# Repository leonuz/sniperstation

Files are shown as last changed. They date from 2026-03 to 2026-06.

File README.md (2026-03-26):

# SniperStation

Automatic irrigation system and weather station for two succulent planters located outdoors in Orlando, Florida.

**SucuFer** — Fernanda's succulent, planted April 22, 2024
**SucuRod** — Rodrigo's succulent, planted April 22, 2024

Monitors environmental conditions (temperature, humidity, light, soil moisture) and waters automatically based on sensor readings. Provides a color touchscreen dashboard (CYD), web dashboard (Grafana), Telegram push alerts, and full historical data logging.

---

## System Overview

```
[OUTSIDE]                                   [INSIDE]
Station-485 (main controller)               CYD ESP32-2432S028 x2
├── BH1750 light sensor    → Port A1        ├── Master Bedroom (SHT30 on CN1)
├── SHT30 outdoor          → Port A2        └── Kids Bedroom   (SHT30 on CN1)
├── Earth Sensor SucuFer   → Port B1                │
├── Earth Sensor SucuRod   → Port B2                │
├── Relay → Pump SucuFer   → Port C1                │
├── Relay → Pump SucuRod   → Port C2                │
└── XKC-Y25 water level    → Port B/C               │
          │                                         │
          └────────── WiFi → MQTT ──────────────────┘
                            │
                     [Proxmox LXC]
                     ├── Mosquitto (MQTT broker)
                     ├── InfluxDB 2.x (time-series database)
                     ├── Grafana (web/mobile dashboard)
                     └── Telegram Bot (push alerts)
```

---

## The Plants

| Plant | Owner | Age | Planted |
|---|---|---|---|
| SucuFer | Fernanda | ~2 years | April 22, 2024 |
| SucuRod | Rodrigo | ~2 years | April 22, 2024 |

The CYD touchscreen detail view for each plant displays the owner's photo with their succulent as the background, along with planting date and current soil moisture.

---

## Hardware Requirements

| Component | Model | Status |
|---|---|---|
| Main controller | M5Stack Station-485 | Have it |
| Light sensor | DLight BH1750 | Have it |
| Temp/humidity x2 | SHT30 IOT-TH02 | Purchased |
| Grove↔Dupont cable | HY2.0-4P to 2.54mm | Purchased |
| Peristaltic pumps x2 | DC 12-24V, 80mA | Purchased — arriving late April |
| Water level sensor | XKC-Y25-V + DFRobot driver | Purchased |
| Soil sensors x2 | M5Stack Earth Sensor | Purchased |
| Relay modules x2 | M5Stack Mini 3A Relay | Purchased |
| Indoor display x2 | CYD ESP32-2432S028 | Purchased — arriving Saturday |
| DC adapter | 12V 2A, 5.5mm jack | **Pending purchase** |
| Outdoor enclosure | IP65+, ventilated | **Pending purchase** |
| Indoor enclosure x2 | Custom 3D printed | **Pending design** |

Full BOM → [hardware/BOM.md](hardware/BOM.md)

---

## Software Stack

| Service | Port | Role |
|---|---|---|
| Mosquitto | 1883 | MQTT broker |
| InfluxDB 2.x | 8086 | Time-series database |
| Grafana | 3000 | Web/mobile dashboard |
| Telegram Bot | — | Push notifications |

All services run in a single Proxmox LXC container.

---

## Repository Structure

```
sniperstation/
├── hardware/
│   ├── BOM.md                        # Full bill of materials
│   ├── schematics/                   # Wiring diagrams
│   ├── datasheets/                   # Component datasheet references
│   └── enclosure/                    # Enclosure specifications + OpenSCAD
├── firmware/
│   ├── station485/                   # Arduino IDE — ESP32 (Station-485)
│   └── cyd_indoor/                   # Arduino IDE — CYD ESP32 (indoor x2)
├── software/
│   ├── mosquitto/                    # Broker config
│   ├── influxdb/                     # Database setup
│   ├── grafana/                      # Dashboard JSON exports
│   └── telegram_bot/                 # Alert bot
├── assets/
│   └── photos/                       # SucuFer + SucuRod plant photos (CYD backgrounds)
├── README.md
├── ROADMAP.md
├── TODO.md
└── CHANGELOG.md
```

---

## Irrigation Logic

```
Every 6 hours (via RTC BM8563):
  FOR each plant (SucuFer, SucuRod):
    IF soil_moisture < dry_threshold:
      IF air_humidity < 85% (not raining):
        IF water_available == TRUE:
          activate_pump(plant, 20 seconds)   // ~33ml at 100ml/min
          wait 30 minutes
          re-read soil_moisture
          IF still_dry: send Telegram alert
        ELSE:
          send Telegram alert "Water tank empty"
```

Pump flow reference: ~100 ml/min at 12V → 20 seconds = ~33 ml

---

## Soil Moisture Thresholds (calibrate with actual planters)

| State | Range | Action |
|---|---|---|
| Dry | < 30% | Irrigate |
| Moist | 30–60% | No action |
| Wet | > 60% | Alert — overwatering risk |

---

## Telegram Alerts

- Irrigation executed (SucuFer / SucuRod + ml delivered)
- Water tank empty
- Soil dry for more than 24h
- Outdoor temperature > 38°C (Orlando extreme heat)
- Sensor disconnected / read error

---

## CYD Touchscreen UI

| View | Content |
|---|---|
| Screensaver | Logo + compact temp summary all rooms |
| Main view | All sensors: exterior + master + kids + SucuFer + SucuRod |
| SucuFer detail | Fernanda's photo background + soil moisture + last watered + plant age |
| SucuRod detail | Rodrigo's photo background + soil moisture + last watered + plant age |

---

## Important Notes

### Orlando Heat
Station-485 max operating temperature is **60°C**. In direct Florida summer sun, enclosures can exceed this easily.
**Mandatory:** install in shade + passive or active ventilation. A 5V fan from inventory can be added if needed.

### GPIO Constraint — Port B2
Uses ESP32 GPIO G36, which **cannot be configured as OUTPUT**.
Earth Sensor SucuRod is read-only (analog input) — correct for this use case.
**Never connect a relay to Port B.**

### I2C Shared Bus (Ports A1/A2)
BH1750 (address 0x23) and SHT30 (address 0x44) share the same I2C bus on G32/G33.
Different addresses — no conflict.

---

## License

Open Hardware — CERN OHL v2 Permissive
Software — MIT

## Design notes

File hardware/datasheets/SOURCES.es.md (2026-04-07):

# Fuentes de Datasheets — SniperStation

Documentación oficial y datasheets de todos los componentes usados en este proyecto.

---

## Controlador Principal

### M5Stack Station-485
- **Página del producto:** https://docs.m5stack.com/en/base/station_485
- **Datasheet ESP32-D0WDQ6:** https://www.espressif.com/sites/default/files/documentation/esp32_datasheet_en.pdf
- **Manual técnico ESP32:** https://www.espressif.com/sites/default/files/documentation/esp32_technical_reference_manual_en.pdf
- **Datasheet RTC BM8563:** https://www.nxp.com/docs/en/data-sheet/PCF8563.pdf *(BM8563 es compatible con PCF8563)*

---

## Sensores

### DLight BH1750 — Sensor de Luz
- **Datasheet:** https://www.mouser.com/datasheet/2/348/bh1750fvi-e-186247.pdf
- **Dirección I2C:** 0x23 (ADDR bajo) / 0x5C (ADDR alto)
- **Especificación clave:** 1–65535 lx, resolución de 16 bits

### SHT30 IOT-TH02 — Temperatura y Humedad
- **Datasheet Sensirion SHT30:** https://sensirion.com/media/documents/213E6A3B/63A5A569/Datasheet_SHT3x_DIS.pdf
- **Dirección I2C:** 0x44 (ADDR bajo) / 0x45 (ADDR alto)
- **Especificaciones clave:** Temp ±0.3°C, Humedad ±2% RH, alimentación 2.15–5.5V

### M5Stack Earth Sensor — Humedad de Suelo
- **Página del producto:** https://docs.m5stack.com/en/unit/earth
- **Salida:** Analógica (0–3.3V) + digital de umbral (ajustable por potenciómetro)
- **Nota clave:** Requiere calibración con el tipo de suelo real

### XKC-Y25-V — Sensor de Nivel de Agua Sin Contacto
- **Página del producto XKC-Y25-V:** https://www.xkc.com.cn/en/product/XKC-Y25-V.html
- **Wiki DFRobot:** https://wiki.dfrobot.com/Non-contact_Liquid_Level_Sensor_XKC-Y25_T12V_SKU__SEN0204
- **Especificaciones clave:** 5–24V, salida digital, funciona en paredes de plástico/vidrio ≤ 3mm, 4 niveles de sensibilidad

---

## Actuadores

### M5Stack Mini Relay 3A
- **Página del producto:** https://docs.m5stack.com/en/unit/mini_relay
- **Especificaciones clave:** 3A/30VDC, 3A/125VAC, control Grove HY2.0, LOW = OFF, HIGH = ON

### Bomba Peristáltica 12V DC
- El datasheet varía según el proveedor. Especificaciones clave verificadas:
  - Voltaje de operación: 12–24V DC
  - Caudal: ~100 ml/min a 12V
  - Corriente: ~80mA a 12V
  - Reversible por inversión de polaridad
  - Tuberías: silicona, aptas para alimentos

---

## Controlador Interior

### ESP8266 NodeMCU CP2102 (ESP-12E)
- **Datasheet ESP8266:** https://www.espressif.com/sites/default/files/documentation/0a-esp8266ex_datasheet_en.pdf
- **Referencia técnica ESP8266:** https://www.espressif.com/sites/default/files/documentation/esp8266-technical_reference_en.pdf
- **Referencia pinout NodeMCU:** https://components101.com/development-boards/nodemcu-esp8266-pinout-features-and-datasheet
- **Bridge USB-UART CP2102:** https://www.silabs.com/documents/public/data-sheets/CP2102-9.pdf

---

## Componentes de Soporte

### Diodo Rectificador 1N4007 (protección flyback)
- **Datasheet:** https://www.vishay.com/docs/88503/1n4007.pdf
- **Uso:** Diodo flyback/freewheeling en cargas inductivas (motores de bomba)

### L293D H-Bridge Motor Driver (opcional — bombas reversibles)
- **Datasheet:** https://www.ti.com/lit/ds/symlink/l293d.pdf
- **Uso:** Si se necesita control bidireccional de bomba (drenar tuberías después del riego)

### MCP3008 ADC (opcional — expansión)
- **Datasheet:** https://ww1.microchip.com/downloads/en/DeviceDoc/21295d.pdf
- **Uso:** ADC SPI de 8 canales y 10 bits para ampliar entradas analógicas

---

## Referencias de Software / Protocolo

### Protocolo MQTT
- **Especificación MQTT 3.1.1:** https://docs.oasis-open.org/mqtt/mqtt/v3.1.1/os/mqtt-v3.1.1-os.html

### InfluxDB 2.x
- **Documentación:** https://docs.influxdata.com/influxdb/v2/

### Grafana
- **Documentación:** https://grafana.com/docs/grafana/latest/

### Mosquitto MQTT Broker
- **Documentación:** https://mosquitto.org/documentation/

---

## Estándares Referenciados

| Estándar | Descripción |
|---|---|
| CERN OHL v2 Permissive | Licencia de hardware abierto usada en este proyecto |
| Especificación I2C | https://www.nxp.com/docs/en/user-guide/UM10204.pdf |
| Estándar conector Grove | HY2.0-4P, paso 2mm, orden de pines: GND/VCC/GPIO_B/GPIO_A |

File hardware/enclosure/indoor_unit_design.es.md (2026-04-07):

# Unidad Interior — Especificación de Enclosure

**Unidades:** 2 (idénticas — Habitación Principal + Habitación de los Niños)
**Material:** PLA (estándar, suficiente para uso interior)
**Montaje:** Montaje en pared
**Color de impresión:** Blanco o gris claro recomendado (combina con la carcasa del SHT30)

---

## Componentes a Alojar

| Componente | Dimensiones PCB | Notas |
|---|---|---|
| ESP8266 NodeMCU CP2102 | 49 x 26 x 12mm | Micro-USB en el extremo corto (inferior) |
| OLED SSH1106 1.3" | 38.5 x 23 x 4mm | Visible a través de la ventana frontal |
| Sensor táctil TTP223 | 24 x 14 x 3mm | Accesible a través del orificio frontal |
| SHT30 (con carcasa) | ~35 x 20 x 12mm | Se monta en la parte superior, expuesto al aire |

---

## Dimensiones Externas

```
Ancho:  70mm
Alto:   90mm  (sin contar el SHT30 en la parte superior)
Fondo:  36mm
Pared:   2mm
```

---

## Distribución de la Cara Frontal

```
         70mm
┌─────────────────────┐  ─┐
│    ┌───────────┐    │   │  14mm margen superior
│    │  [OLED]   │    │   │  Ventana OLED: 35 x 24mm, centrada
│    │  35x24mm  │    │   │  (centrada horizontalmente)
│    └───────────┘    │   │
│                     │   │  90mm alto total
│    ───────────────  │   │  línea separadora (grabada, opcional)
│                     │   │
│       [ ◉ ]         │   │  círculo táctil: 16mm diámetro
│                     │   │
└──────────┬──────────┘  ─┘
           │ ranura USB
     (10mm A x 8mm H)
```

**Ventana OLED:** Recorte rectangular 35 x 24mm, 2mm desde la pared frontal → efecto vidrio
**Área táctil:** Orificio circular de 16mm, centrado horizontalmente, 58mm desde arriba
**Ranura USB:** 10mm A x 8mm H, centrada en el borde inferior — cable sale hacia abajo

---

## Distribución de la Cara Superior

```
         70mm
┌─────────────────────┐
│   ┌─────────────┐   │  Ranura SHT30: 37 x 22mm agujero rectangular
│   │  [SHT30]    │   │  SHT30 queda a nivel con la superficie superior
│   │  entra aquí │   │  ranuras de ventilación apuntan hacia arriba
│   └─────────────┘   │
└─────────────────────┘
```

La carcasa del SHT30 entra desde arriba y se sostiene por fricción o un pequeño tope (0.5mm).
Los cables pasan por el interior del enclosure hasta el NodeMCU.

---

## Distribución de la Cara Trasera

```
         70mm
┌─────────────────────┐
│                     │
│   ●             ●   │  2 agujeros de montaje, 4mm diámetro
│  (15mm desde     )  │  50mm entre centros (horizontal)
│  cada lado)      )  │  40mm desde arriba
│                     │
│                     │
│                     │
└─────────────────────┘
```

**Agujeros de montaje:** 4mm diámetro, avellanado, para tornillos M3 en tacos de pared.
**Alternativa:** Ranuras de ojo de cerradura (colgar en tornillos ya en la pared, sin herramientas para desmontar).

---

## Distribución Interna

```
Vista lateral (sección transversal):
       Frente                Fondo
         │                   │
         │  [OLED]           │
         │   ──────────────  │
         │                   │
         │  [PCB NodeMCU]    │
         │  ─────────────    │   ← NodeMCU sobre separadores de 3mm
         │                   │
         └───────────────────┘
                parte inf
                  │
               ranura USB
```

**Separadores NodeMCU:** 3mm de alto, 4 postes (uno en cada agujero de montaje del PCB NodeMCU).
**Montaje OLED:** Pequeña repisa o 4 postes en el frente, 2mm detrás de la pared frontal.
**TTP223:** Pegado por detrás del agujero táctil sobre una pequeña plataforma.
**Ruteo de cables:** Canal de 5mm en la parte inferior interna para cables I2C + táctil.

---

## Tolerancias

| Característica | Tolerancia |
|---|---|
| Ventana OLED | +0.3mm en todos los lados |
| Ranura SHT30 | +0.4mm en todos los lados (ligero ajuste por fricción) |
| Ranura USB | +1mm A, +0.5mm H |
| Agujero táctil | +0.2mm radio |
| Agujeros de montaje | exacto 4.2mm (holgura M3) |

---

## Orden de Ensamblaje

1. Insertar NodeMCU sobre los separadores
2. Conectar todos los cables (SDA/SCL/táctil/alimentación) antes de cerrar
3. Presionar OLED en la repisa de la ventana frontal desde adentro
4. Insertar TTP223 en la plataforma táctil desde adentro
5. Rutear cables del SHT30 por el canal interno
6. Colocar la carcasa del SHT30 en la ranura superior desde arriba
7. Cerrar la tapa (encaje o 2x tornillos M2 en los lados)

---

## Modelo 3D — Herramientas

Software recomendado para crear el STL:

| Herramienta | Costo | Dificultad | Notas |
|---|---|---|---|
| **TinkerCAD** | Gratis (navegador) | Fácil | Ideal para esta caja — arrastrar y soltar |
| **OpenSCAD** | Gratis (escritorio) | Medio | Basado en código, paramétrico — Claude puede escribirlo |
| **FreeCAD** | Gratis (escritorio) | Difícil | CAD completo, excesivo para una caja simple |
| **Fusion 360** | Gratis (personal) | Medio | Profesional, bueno para formas complejas |

**Recomendación:** OpenSCAD — Claude Code puede escribir el archivo `.scad` directamente desde esta especificación.

---

## Configuración de Impresión (recomendada)

| Parámetro | Valor |
|---|---|
| Altura de capa | 0.2mm |
| Relleno | 20% |
| Paredes | 3 perímetros |
| Soporte | No necesario (diseño sin voladizos) |
| Material | PLA |
| Peso estimado | ~30–40g por unidad |
| Tiempo estimado | ~2–3h por unidad |

---

## Servicios de Impresión (Orlando, FL)

| Servicio | Tipo | Costo Est. | Tiempo |
|---|---|---|---|
| **Orange County Library** | Local, gratis/barato | $1–3 | Misma semana (reservar turno) |
| **Treatstock.com** | Red local USA | $8–15 por unidad | 3–7 días |
| **JLCPCB.com** | En línea (China) | $3–5 por unidad + envío | 10–15 días |
| **Craftcloud3d.com** | Comparador de precios | variable | variable |

**Recomendado para primera iteración:** Orange County Library o Treatstock (entrega rápida para probar ajuste).
**Para versión final:** JLCPCB si el diseño está confirmado (más barato por unidad).

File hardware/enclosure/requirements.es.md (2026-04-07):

# Requisitos de Enclosure — Unidad Exterior SniperStation

**Entorno:** Exterior, Orlando FL — posible exposición total al sol, lluvia, humedad, extremos de temperatura

---

## Requisitos de Protección

| Parámetro | Mínimo | Notas |
|---|---|---|
| Clasificación IP | IP65 | A prueba de polvo + protegido contra chorros de agua |
| Temp. de operación (ambiente) | 0–55°C | Temp máxima interna M5Stack Station-485 es 60°C |
| Resistencia UV | Sí | El plástico se degrada rápidamente bajo el sol de Florida |
| Montaje | Mural o en poste | Cerca de los materos, evitar sol directo en el enclosure |

---

## Dimensiones Internas (mínimas)

| Dimensión | Mínimo |
|---|---|
| Largo | 150mm |
| Ancho | 120mm |
| Alto | 80mm |

**Justificación:** La huella del Station-485 es 54 x 54mm. Los módulos de relay x2 agregan ~30mm. El cableado y conectores necesitan ~40mm de espacio.

---

## Ventilación

El ESP32 del Station-485 genera calor. En un enclosure sellado bajo el sol de verano en Florida, la temperatura interna puede superar los 60°C (temperatura máxima del controlador).

**Obligatorio:** Al menos una de estas estrategias de ventilación:

1. **Ventilación pasiva:** Enclosure con persianas/ranuras en la parte inferior y superior (efecto chimenea). Las ranuras deben tener baffles para evitar ingreso de agua (persianas compatibles IP65).
2. **Ventilación activa:** Ventilador pequeño de 5V (disponible en el kit SunFounder) con toma de aire filtrada. Ventilador controlado por termistor — activar por encima de 45°C interno.

**Recomendado:** Instalar en **sombra permanente** (pared norte, bajo alero, o en lugar sombreado). Esta es la medida de gestión térmica más efectiva.

---

## Puntos de Entrada de Cables

Penetraciones requeridas en las paredes del enclosure:

| Entrada | Cable/Tubería | Tipo de Prensaestopa |
|---|---|---|
| Alimentación | Cable barrel jack 12V DC | Prensaestopa PG7 |
| Grove A1 | Sensor BH1750 | Prensaestopa PG7 |
| Grove A2 | SHT30 exterior | Prensaestopa PG7 |
| Grove B1 | Sensor de tierra 1 | Prensaestopa PG7 |
| Grove B2 | Sensor de tierra 2 | Prensaestopa PG7 |
| Relay C1 | Cable bomba 1 | Prensaestopa PG9 |
| Relay C2 | Cable bomba 2 | Prensaestopa PG9 |
| XKC-Y25 | Sensor nivel de agua | Prensaestopa PG7 |
| USB-A | VCC XKC-Y25 (5V) | Ruteo interno si es posible |

**Recomendado:** Prensaestopas impermeables en todas las entradas. Sellar con silicona después de rutear.

---

## Consideraciones de Montaje

- Montar **lejos del sol directo** — preferible norte o este, bajo alero
- Montar **sobre el nivel del suelo** — mínimo 30cm para evitar salpicaduras
- Asegurarse de tener agujeros de drenaje en la parte inferior del enclosure para evitar acumulación de agua si entra humedad
- Considerar el ruteo de cables — los cables Grove tienen máximo ~50cm, colocar el enclosure **cerca de los materos**

---

## Notas sobre Gestión Térmica

Peor caso medido para Orlando, FL:
- Temperatura ambiente exterior: 38°C (pico de verano)
- Sol directo en enclosure metálico: la superficie puede llegar a 70–80°C
- Dentro de un enclosure cerrado bajo sol directo: hasta 90°C posible

**Rango de operación de los componentes:**

| Componente | Temp. Máxima Nominal |
|---|---|
| Station-485 (ESP32) | 60°C |
| SHT30 | 125°C |
| BH1750 | 85°C |
| Sensores de tierra | 85°C |
| Relay M5Stack | 85°C |

**Acción requerida:** Colocar en sombra. Si la sombra no es posible, agregar ventilador forzado.

---

## Productos Recomendados (términos de búsqueda en Amazon)

- "IP65 weatherproof enclosure 150x120x80mm"
- "waterproof junction box with ventilation"
- "PG7 cable gland waterproof" (paquete de 10)
- "PG9 cable gland waterproof" (paquete de 10)

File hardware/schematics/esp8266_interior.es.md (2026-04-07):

# ESP8266 NodeMCU — Conexiones Unidades Interiores

**Unidades:** 2 unidades idénticas — Habitación Principal + Habitación de los Niños
**Controlador:** ESP8266 NodeMCU v3 CP2102
**Propósito:** Leer temp/humedad interior, mostrar en OLED, publicar en MQTT por WiFi
**Alimentación:** USB 5V (desde cargador USB)

---

## Componentes por Unidad

| Componente | Modelo | Dirección I2C | Interfaz |
|---|---|---|---|
| Sensor temp/humedad | SHT30 IOT-TH02 | 0x44 | I2C |
| Display OLED | SSH1106 1.3" 128x64 | 0x3C | I2C |
| Sensor táctil | TTP223 capacitivo | — | Digital ENTRADA |

Sin conflicto de dirección I2C. ✅

---

## Diagrama de Conexiones

```
ESP8266 NodeMCU CP2102
┌────────────────────────────────────────────────────────────┐
│                                                            │
│  3V3  ──────────────────────────────────► SHT30 VCC       │
│  3V3  ──────────────────────────────────► OLED VCC        │
│  3V3  ──────────────────────────────────► TTP223 VCC      │
│  GND  ──────────────────────────────────► SHT30 GND       │
│  GND  ──────────────────────────────────► OLED GND        │
│  GND  ──────────────────────────────────► TTP223 GND      │
│                                                            │
│  D2 (GPIO4) ──── pull-up 10KΩ a 3V3 ──► Bus SDA          │
│                                           ├── SHT30 SDA   │
│                                           └── OLED SDA    │
│                                                            │
│  D1 (GPIO5) ──── pull-up 10KΩ a 3V3 ──► Bus SCL          │
│                                           ├── SHT30 SCL   │
│                                           └── OLED SCL    │
│                                                            │
│  D5 (GPIO14) ───────────────────────────► TTP223 OUT      │
│                                                            │
│  USB (micro) ───────────────────────────► Alimentación 5V │
└────────────────────────────────────────────────────────────┘
```

---

## Conexión SHT30

```
ESP8266 / Bus I2C          SHT30 IOT-TH02 (cables sueltos)
──────────────────────────────────────────────────────────
3V3             ──────►  Rojo    (VCC)
GND             ──────►  Negro   (GND)
Bus SDA (D2)    ──────►  Blanco  (SDA)  ⚠️ COLORES CRUZADOS vs estándar Grove
Bus SCL (D1)    ──────►  Amarillo (SCL) ⚠️ COLORES CRUZADOS vs estándar Grove
```

> **⚠️ Mapeo de colores SHT30 IOT-TH02:** Blanco = SDA, Amarillo = SCL.
> Opuesto al estándar Grove HY2.0. Verificar antes de encender.

---

## Conexión OLED SSH1106

```
ESP8266 / Bus I2C          SSH1106 1.3" OLED (4 pines)
──────────────────────────────────────────────────────────
3V3             ──────►  VCC
GND             ──────►  GND
Bus SDA (D2)    ──────►  SDA
Bus SCL (D1)    ──────►  SCL
```

- Librería: **U8g2** (`U8G2_SH1106_128X64_NONAME_F_HW_I2C`)
- Dirección I2C: 0x3C

---

## Conexión Sensor Táctil TTP223

```
ESP8266                   TTP223
──────────────────────────────────────────────────────────
3V3             ──────►  VCC
GND             ──────►  GND
D5 (GPIO14)     ──────►  OUT  (HIGH al tocar)
```

- Configurado como ENTRADA en el firmware
- Activa la pantalla desde el salvapantallas

---

## Resistencias Pull-up I2C

Se requieren pull-ups externos de 10KΩ en SDA y SCL (los pull-ups internos del ESP8266 son insuficientes para I2C confiable con dos dispositivos).

```
3V3 ──── 10KΩ ──── D2 (Bus SDA)
3V3 ──── 10KΩ ──── D1 (Bus SCL)
```

---

## Resumen GPIO

| GPIO | Etiqueta NodeMCU | Función | Dirección |
|---|---|---|---|
| GPIO4 | D2 | I2C SDA — SHT30 + OLED | E/S |
| GPIO5 | D1 | I2C SCL — SHT30 + OLED | E/S |
| GPIO14 | D5 | Señal táctil TTP223 | ENTRADA |

---

## Comportamiento de Pantalla y Lógica de Brillo

| Estado | Disparador | Brillo | Contenido |
|---|---|---|---|
| Salvapantallas | Por defecto / timeout 30s | 10/255 | Logo SniperStation (bitmap) |
| Activo | Toque detectado | 200/255 | Temp + humedad + fecha + hora |
| Modo noche | 00:00 – 06:00 (NTP) | 0 (pantalla apagada) | — |

**Máquina de estados:**
```
SALVAPANTALLAS ──── toque ────► ACTIVO (temporizador 30s inicia)
       ▲                              │
       └──────── timeout / noche ─────┘
```

Brillo controlado via `setContrast()` de U8g2 (mapea al registro SSH1106 0x81, 0–255).

---

## Distribución OLED — Modo Activo (128x64)

```
┌────────────────────────────┐
│ [SS] SniperStation           │  ← logo pequeño 16x16 + título (línea 1)
│ ──────────────────────── │  ← separador
│  25.3°C        72% RH      │  ← datos del sensor (línea 3)
│  Mar 25, 2026  14:23       │  ← fecha + hora NTP (línea 4)
└────────────────────────────┘
```

## Distribución OLED — Modo Salvapantallas (128x64)

```
┌────────────────────────────┐
│                            │
│      [LOGO 48x48]          │  ← bitmap grande centrado
│      SniperStation           │  ← nombre centrado debajo del logo
│                            │
└────────────────────────────┘
```

---

## Fecha / Hora — NTP

No se necesita hardware RTC. Hora sincronizada por WiFi al iniciar y cada hora.

- Servidor: `pool.ntp.org`
- Zona horaria: `America/New_York` (Orlando, FL — UTC-5 / UTC-4 DST)
- Librería: `NTPClient` + `ESP8266WiFi`
- Sin WiFi: mostrar última hora conocida + indicador `(sin sync)`

---

## Topics MQTT

### Unidad Habitación Principal (`ROOM_ID = "master"`)

| Topic | Valor | Frecuencia |
|---|---|---|
| `sniperstation/interior/master/temperatura` | float (°C) | Cada 60s |
| `sniperstation/interior/master/humedad` | float (%) | Cada 60s |

### Unidad Habitación de los Niños (`ROOM_ID = "kids"`)

| Topic | Valor | Frecuencia |
|---|---|---|
| `sniperstation/interior/kids/temperatura` | float (°C) | Cada 60s |
| `sniperstation/interior/kids/humedad` | float (%) | Cada 60s |

El firmware es idéntico para ambas unidades. Solo difiere el `ROOM_ID`.

---

## Enclosure Físico

Enclosure impreso en 3D a medida (mismo diseño para ambas unidades). Contiene:
- ESP8266 NodeMCU (49 x 26mm)
- OLED 1.3" SSH1106 — recorte/ventana en la cara frontal
- Sensor táctil TTP223 — cara frontal, accesible con el dedo
- SHT30 — parte superior del enclosure, carcasa expuesta al aire del cuarto

Ver `hardware/enclosure/indoor_unit_design.md` para especificaciones completas.

---

## Nota sobre Alimentación

- Alimentación por micro-USB (cargador USB 5V)
- SHT30 y OLED alimentados solo desde el pin 3V3
- **No** alimentar SHT30 desde 5V en esta unidad

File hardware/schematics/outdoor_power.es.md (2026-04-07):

# Distribución de Alimentación Exterior — SniperStation

**Fuente de alimentación:** Adaptador DC 12V 2A (conector barrel 5.5×2.1mm)
**Carga total:** ≤400mA @ 12V peor caso (margen de seguridad 5×)

---

## Árbol de Alimentación

```
┌─────────────────────────────────────────────────────────────────┐
│           ADAPTADOR DC 12V 2A (barrel 5.5×2.1mm)               │
│                         │                                        │
│               ┌─────────┘                                        │
│               │                                                   │
│               ▼                                                   │
│      ┌─────────────────┐   ┌─────────────────┐                  │
│      │  Wago 221-415   │   │  Wago 221-415   │                  │
│      │   RIEL +12V     │   │    RIEL GND     │                  │
│      │                 │   │                 │                  │
│      │ ENT:  Adapt. +  │   │ ENT:  Adapt. -  │                  │
│      │ SAL1: Station ──┤   ├── Station-485 - │                  │
│      │ SAL2: Relay1 COM┤   ├── Bomba 1 (-)  │                  │
│      │ SAL3: Relay2 COM┤   ├── Bomba 2 (-)  │                  │
│      │ SAL4: Buck ENT +┤   ├── Buck ENT -   │                  │
│      └─────────────────┘   └─────────────────┘                  │
│               │                                                   │
│       ┌───────┼───────────────────────────┐                      │
│       │       │                           │                      │
│       ▼       ▼                           ▼                      │
│  ┌─────────────────┐            ┌──────────────────┐            │
│  │  Station-485    │            │ Convertidor Buck  │            │
│  │  9–24V PWR485   │            │ 12V→5V           │            │
│  │                 │            │ (LM2596/MP1584)  │            │
│  │  5V interno ────┼──► Grove   │  5V salida ──────┼──► TimerCam X (USB-C)  │
│  │                 │    ├── BH1750  (~1mA)          │    activo: ~180mA      │
│  │                 │    ├── SHT30   (~1mA)          │    sleep:  ~0.001mA    │
│  │                 │    ├── Tierra×2 (~5mA c/u)    └──────────────────┘    │
│  │                 │    └── Relays  (~70mA activo)                           │
│  │  USB-A 5V ──────┼──► XKC-Y25 + driver (~10mA)                           │
│  │                 │                                                          │
│  │  Relay 1 NO ────┼──► Bomba SucuFer + (~80mA)                            │
│  │  Relay 2 NO ────┼──► Bomba SucuRod + (~80mA, nunca simultáneas)         │
│  └─────────────────┘                                                         │
└─────────────────────────────────────────────────────────────────────────────┘
```

---

## Por Qué un Convertidor Buck Separado para TimerCam X

La salida USB-A del Station-485 ya está usada por la placa driver XKC-Y25.
Agregar la TimerCam X al mismo puerto USB-A puede generar inestabilidad cuando la cámara
se activa y consume ~180mA.

**Solución:** Un convertidor mini buck 12V→5V dedicado para la TimerCam X.

**Parte recomendada:** Módulo mini DC-DC step-down (LM2596 o MP1584)
- Entrada: 12V
- Salida: 5V fijo
- Corriente máxima: 2A (muy por encima de los 180mA pico de la TimerCam)
- Costo: ~$1–3 en Amazon
- Tamaño: ~23×17mm — cabe fácilmente en el enclosure IP65

---

## Presupuesto de Potencia (Exterior)

| Componente | Voltaje | Corriente (reposo) | Corriente (pico) | Notas |
|---|---|---|---|---|
| Station-485 | 12V | 120mA | 200mA | WiFi activo = 161mA |
| Bomba SucuFer | 12V | 0 | 100mA | via Relay 1 — nunca simultánea con Bomba 2 |
| Bomba SucuRod | 12V | 0 | 100mA | via Relay 2 — nunca simultánea con Bomba 1 |
| BH1750 | 5V (interno) | 0.2mA | 0.2mA | despreciable |
| SHT30 exterior | 5V (interno) | 0.8mA | 0.8mA | despreciable |
| Sensor Tierra ×2 | 5V (interno) | 5mA c/u | 5mA c/u | |
| XKC-Y25 + driver | 5V USB-A | 10mA | 10mA | USB-A del Station-485 |
| Relay ×2 | 5V (interno) | ~0mA | 70mA c/u | solo cuando bomba activa |
| TimerCam X | 5V (buck) | 0.001mA | 180mA | sleep 2µA, activo ~180mA |
| **TOTAL PEOR CASO** | **12V** | | **~380mA** | Station-485 WiFi + 1 bomba activa |

**Capacidad del adaptador:** 12V 2A = 2000mA
**Consumo peor caso:** ~380mA
**Margen de seguridad: 5×** ✅

> Peor caso: Station-485 WiFi activo (161mA) + 1 bomba (80mA) + TimerCam activa (180mA) ≈ **421mA**
> Aún dentro de la capacidad de 2A. ✅

---

## Componentes de Protección

| Componente | Valor | Ubicación | Propósito |
|---|---|---|---|
| Diodo 1N4007 | — | En bornes de cada bomba | Protección flyback (carga inductiva) |
| Capacitor electrolítico | 10µF | Cerca de salidas de relay | Filtro de ruido de alimentación |

---

## Notas de Cableado

- Todas las conexiones exteriores dentro del enclosure IP65
- Se requieren prensaestopas para: entrada 12V, cables Grove a sensores, tuberías, alimentación TimerCam X
- La TimerCam X se monta en la pared del enclosure con ventana de acrílico/vidrio para el lente
- Cable USB-C del convertidor buck a TimerCam X — mantener corto (≤30cm dentro del enclosure)

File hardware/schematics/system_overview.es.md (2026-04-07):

# Visión General del Sistema — SniperStation

```
┌─────────────────────────────────────────────────────────────────────────────┐
│                              UNIDAD EXTERIOR                                │
│                                                                             │
│  ┌─────────────────────────────────────────────────────┐                   │
│  │               M5Stack Station-485                    │                   │
│  │                    (ESP32)                           │                   │
│  │                                                      │                   │
│  │  Puerto A1 ──── BH1750 (Luz, I2C 0x23)             │                   │
│  │  Puerto A2 ──── SHT30 exterior (Temp/Hum, I2C 0x44)│                   │
│  │  Puerto B1 ──── Sensor Tierra 1 (SucuFer, Analógico)│                   │
│  │  Puerto B2 ──── Sensor Tierra 2 (SucuRod, Analógico)│                   │
│  │  Puerto C1 ──── Relay 1 ──── Bomba 1 (SucuFer)     │                   │
│  │  Puerto C2 ──── Relay 2 ──── Bomba 2 (SucuRod)     │                   │
│  │  GPIO  ────── XKC-Y25 (Nivel agua, Digital)         │                   │
│  │                                                      │                   │
│  │  PWR485 ───── Adaptador DC 12V 2A                   │                   │
│  │  WiFi ──────────────────────────────────────────────┼──► Broker MQTT   │
│  └─────────────────────────────────────────────────────┘                   │
│                                                                             │
│  ┌──────────┐  ┌──────────┐  ┌─────────────────┐  ┌──────────────────┐    │
│  │ Bomba 1  │  │ Bomba 2  │  │ Sensor XKC-Y25  │  │ TimerCam X       │    │
│  │ 12V 80mA │  │ 12V 80mA │  │ + driver DFRobot│  │ OV3660 3MP       │    │
│  │ → SucuFer│  │ → SucuRod│  │ Recipiente agua │  │ ESP32 + batería  │    │
│  │          │  │          │  │ (sin contacto)  │  │ WiFi → HTTP/MQTT │    │
│  │ FOV 66.5°        │    │
│  │ sleep: 2µA       │    │
│  └──────────┘  └──────────┘  └─────────────────┘  └──────────────────┘    │
└─────────────────────────────────────────────────────────────────────────────┘

┌─────────────────────────────────────────────────────────────────────────────┐
│                      UNIDAD INTERIOR — HABITACIÓN PRINCIPAL                 │
│                                                                             │
│  ┌─────────────────────────────────────────────────────┐                   │
│  │          CYD ESP32-2432S028  (ROOM_ID=master)        │                   │
│  │                                                      │                   │
│  │  CN1 GPIO21 ── I2C SDA ── SHT30 (0x44)              │                   │
│  │  CN1 GPIO22 ── I2C SCL ── SHT30 (0x44)              │                   │
│  │  Pull-ups 10KΩ en SDA + SCL                         │                   │
│  │                                                      │                   │
│  │  [TFT 2.8" 240x320 color] — integrado               │                   │
│  │  [XPT2046 táctil resistivo] — integrado             │                   │
│  │  [SHT30 con carcasa] ────── parte superior, expuesto│                   │
│  │                                                      │                   │
│  │  WiFi ──────────────────────────────────────────────┼──► Broker MQTT   │
│  └─────────────────────────────────────────────────────┘                   │
└─────────────────────────────────────────────────────────────────────────────┘

┌─────────────────────────────────────────────────────────────────────────────┐
│                   UNIDAD INTERIOR — HABITACIÓN DE LOS NIÑOS                 │
│                                                                             │
│  ┌─────────────────────────────────────────────────────┐                   │
│  │          CYD ESP32-2432S028  (ROOM_ID=kids)          │                   │
│  │                                                      │                   │
│  │  CN1 GPIO21 ── I2C SDA ── SHT30 (0x44)              │                   │
│  │  CN1 GPIO22 ── I2C SCL ── SHT30 (0x44)              │                   │
│  │  Pull-ups 10KΩ en SDA + SCL                         │                   │
│  │                                                      │                   │
│  │  [TFT 2.8" 240x320 color] — integrado               │                   │
│  │  [XPT2046 táctil resistivo] — integrado             │                   │
│  │  [SHT30 con carcasa] ────── parte superior, expuesto│                   │
│  │                                                      │                   │
│  │  WiFi ──────────────────────────────────────────────┼──► Broker MQTT   │
│  └─────────────────────────────────────────────────────┘                   │
└─────────────────────────────────────────────────────────────────────────────┘

┌─────────────────────────────────────────────────────────────────────────────┐
│                         PROXMOX LXC (Servidor)                              │
│                                                                             │
│  ┌──────────────┐  ┌──────────────┐  ┌──────────┐  ┌──────────────────┐   │
│  │  Mosquitto   │  │  InfluxDB    │  │ Grafana  │  │  Bot Telegram    │   │
│  │  Broker MQTT │→ │  2.x         │→ │  :3000   │  │  (Python)        │   │
│  │  :1883       │  │  :8086       │  │          │  │                  │   │
│  └──────────────┘  └──────────────┘  └──────────┘  └──────────────────┘   │
│         ▲                                                    ▲              │
│         │                                                    │              │
│    Datos MQTT desde                                  Alertas + comandos     │
│    Station-485 + ESP8266                             hacia/desde teléfono   │
└─────────────────────────────────────────────────────────────────────────────┘
```

## Flujo de Datos

```
Lectura de sensores (Station-485)
    │
    ├── Cada 60 segundos: publicar datos de sensores en topics MQTT
    │
    ├── Cada 6 horas: evaluar lógica de riego
    │       │
    │       ├── humedad_suelo < 30% Y humedad_aire < 85% Y agua_disponible
    │       │       └── activar bomba (20s) → esperar 30min → re-verificar
    │       │
    │       └── condición no cumplida → omitir
    │
    └── Umbral superado → publicar topic de alerta → Bot Telegram → teléfono

Lectura de sensores (CYD ESP32 interior)
    │
    └── Cada 60 segundos: publicar temp/hum interior en topics MQTT

TimerCam X (exterior, ciclo de sueño profundo)
    │
    ├── RTC despierta la cámara cada 4h (configurable)
    ├── Toma foto → HTTP POST → almacenamiento LXC Proxmox
    ├── Publica evento MQTT → panel Grafana se actualiza
    └── Vuelve a sueño profundo (~2µA)

MQTT → Telegraf/Bridge → InfluxDB → paneles Grafana
```

## Esquema de Topics MQTT

| Topic | Dirección | Tipo | Publicado por |
|---|---|---|---|
| `sniperstation/exterior/temperatura` | SALIDA | float (°C) | Station-485 |
| `sniperstation/exterior/humedad` | SALIDA | float (%) | Station-485 |
| `sniperstation/exterior/luz` | SALIDA | int (lx) | Station-485 |
| `sniperstation/interior/master/temperatura` | SALIDA | float (°C) | ESP8266 master |
| `sniperstation/interior/master/humedad` | SALIDA | float (%) | ESP8266 master |
| `sniperstation/interior/kids/temperatura` | SALIDA | float (°C) | ESP8266 kids |
| `sniperstation/interior/kids/humedad` | SALIDA | float (%) | ESP8266 kids |
| `sniperstation/sucufer/humedad_suelo` | SALIDA | float (%) | Station-485 |
| `sniperstation/sucurod/humedad_suelo` | SALIDA | float (%) | Station-485 |
| `sniperstation/sucufer/bomba` | SALIDA | int (0/1) | Station-485 |
| `sniperstation/sucurod/bomba` | SALIDA | int (0/1) | Station-485 |
| `sniperstation/sucufer/bomba/set` | ENTRADA | int (0/1) | Bot Telegram |
| `sniperstation/sucurod/bomba/set` | ENTRADA | int (0/1) | Bot Telegram |
| `sniperstation/agua/nivel` | SALIDA | int (0/1) | Station-485 |
| `sniperstation/sistema/estado` | SALIDA | string (JSON) | Station-485 |
| `sniperstation/alertas` | SALIDA | string (JSON) | Station-485 |
| `sniperstation/camaras/sucufer/captura` | SALIDA | string (nombre archivo) | TimerCam X |
| `sniperstation/camaras/sucurod/captura` | SALIDA | string (nombre archivo) | TimerCam X (2ª unidad, futuro) |

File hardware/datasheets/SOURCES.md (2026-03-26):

# Component Datasheet Sources — SniperStation

All official documentation and datasheets for components used in this project.

---

## Main Controller

### M5Stack Station-485
- **Product page:** https://docs.m5stack.com/en/base/station_485
- **ESP32-D0WDQ6 datasheet:** https://www.espressif.com/sites/default/files/documentation/esp32_datasheet_en.pdf
- **ESP32 technical reference manual:** https://www.espressif.com/sites/default/files/documentation/esp32_technical_reference_manual_en.pdf
- **RTC BM8563 datasheet:** https://www.nxp.com/docs/en/data-sheet/PCF8563.pdf *(BM8563 is compatible with PCF8563)*

---

## Sensors

### DLight BH1750 — Light Sensor
- **Datasheet:** https://www.mouser.com/datasheet/2/348/bh1750fvi-e-186247.pdf
- **I2C address:** 0x23 (ADDR low) / 0x5C (ADDR high)
- **Key spec:** 1–65535 lx, 16-bit resolution

### SHT30 IOT-TH02 — Temperature & Humidity
- **Sensirion SHT30 datasheet:** https://sensirion.com/media/documents/213E6A3B/63A5A569/Datasheet_SHT3x_DIS.pdf
- **I2C address:** 0x44 (ADDR low) / 0x45 (ADDR high)
- **Key specs:** Temp ±0.3°C, Humidity ±2% RH, 2.15–5.5V supply

### M5Stack Earth Sensor — Soil Moisture
- **Product page:** https://docs.m5stack.com/en/unit/earth
- **Output:** Analog (0–3.3V) + Digital threshold (adjustable via potentiometer)
- **Key note:** Requires calibration with actual soil type

### XKC-Y25-V — Non-Contact Water Level Sensor
- **XKC-Y25-V product page:** https://www.xkc.com.cn/en/product/XKC-Y25-V.html
- **DFRobot driver wiki:** https://wiki.dfrobot.com/Non-contact_Liquid_Level_Sensor_XKC-Y25_T12V_SKU__SEN0204
- **Key specs:** 5–24V, digital output, works on plastic/glass walls ≤ 3mm, 4 sensitivity levels

---

## Actuators

### M5Stack Mini 3A Relay
- **Product page:** https://docs.m5stack.com/en/unit/mini_relay
- **Key specs:** 3A/30VDC, 3A/125VAC, Grove HY2.0 control, LOW = OFF, HIGH = ON

### Peristaltic Pump 12V DC
- Datasheet varies by supplier. Key verified specs:
  - Operating voltage: 12–24V DC
  - Flow rate: ~100 ml/min at 12V
  - Current: ~80mA at 12V
  - Reversible by polarity inversion
  - Tubing: silicone, food-safe

---

## Indoor Controller

### ESP8266 NodeMCU CP2102 (ESP-12E)
- **ESP8266 datasheet:** https://www.espressif.com/sites/default/files/documentation/0a-esp8266ex_datasheet_en.pdf
- **ESP8266 technical reference:** https://www.espressif.com/sites/default/files/documentation/esp8266-technical_reference_en.pdf
- **NodeMCU pinout reference:** https://components101.com/development-boards/nodemcu-esp8266-pinout-features-and-datasheet
- **CP2102 USB-UART bridge:** https://www.silabs.com/documents/public/data-sheets/CP2102-9.pdf

---

## Supporting Components

### 1N4007 Rectifier Diode (flyback protection)
- **Datasheet:** https://www.vishay.com/docs/88503/1n4007.pdf
- **Use:** Flyback/freewheeling diode across inductive loads (pump motors)

### L293D H-Bridge Motor Driver (optional — reversible pumps)
- **Datasheet:** https://www.ti.com/lit/ds/symlink/l293d.pdf
- **Use:** If bidirectional pump control is needed (drain tubing after irrigation)

### MCP3008 ADC (optional — expansion)
- **Datasheet:** https://ww1.microchip.com/downloads/en/DeviceDoc/21295d.pdf
- **Use:** 8-channel 10-bit SPI ADC for expanding analog inputs

---

## Software / Protocol References

### MQTT Protocol
- **MQTT 3.1.1 specification:** https://docs.oasis-open.org/mqtt/mqtt/v3.1.1/os/mqtt-v3.1.1-os.html

### InfluxDB 2.x
- **Documentation:** https://docs.influxdata.com/influxdb/v2/

### Grafana
- **Documentation:** https://grafana.com/docs/grafana/latest/

### Mosquitto MQTT Broker
- **Documentation:** https://mosquitto.org/documentation/

---

## Standards Referenced

| Standard | Description |
|---|---|
| CERN OHL v2 Permissive | Open hardware license used for this project |
| I2C specification | https://www.nxp.com/docs/en/user-guide/UM10204.pdf |
| Grove connector standard | HY2.0-4P, 2mm pitch, pin order: GND/VCC/GPIO_B/GPIO_A |

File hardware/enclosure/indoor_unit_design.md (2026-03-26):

# Indoor Unit Enclosure — Design Specification

**Units:** 2 (identical — Master Bedroom + Kids Bedroom)
**Material:** PLA (standard, sufficient for indoor use)
**Mount:** Wall mount
**Print color:** White or light gray recommended (matches SHT30 casing)

---

## Components to Fit

| Component | PCB Dimensions | Notes |
|---|---|---|
| ESP8266 NodeMCU CP2102 | 49 x 26 x 12mm | Micro-USB on short end (bottom) |
| OLED SSH1106 1.3" | 38.5 x 23 x 4mm | Visible through front window |
| TTP223 touch sensor | 24 x 14 x 3mm | Accessible through front hole |
| SHT30 (cased) | ~35 x 20 x 12mm | Mounts on top, exposed to room air |

---

## External Dimensions

```
Width:  70mm
Height: 90mm  (not counting SHT30 on top)
Depth:  36mm
Wall:    2mm
```

---

## Front Face Layout

```
         70mm
┌─────────────────────┐  ─┐
│    ┌───────────┐    │   │  14mm top margin
│    │  [OLED]   │    │   │  OLED window: 35 x 24mm, centered
│    │  35x24mm  │    │   │  (centered horizontally)
│    └───────────┘    │   │
│                     │   │  90mm total height
│    ───────────────  │   │  separator line (engraved, optional)
│                     │   │
│       [ ◉ ]         │   │  touch circle: 16mm diameter
│                     │   │
└──────────┬──────────┘  ─┘
           │ USB slot
     (10mm W x 8mm H)
```

**OLED window:** 35 x 24mm rectangular cutout, 2mm from front wall → glass effect
**Touch area:** 16mm circular hole, centered horizontally, 58mm from top
**USB slot:** 10mm W x 8mm H, centered at bottom edge — cable exits downward

---

## Top Face Layout

```
         70mm
┌─────────────────────┐
│   ┌─────────────┐   │  SHT30 slot: 37 x 22mm rectangular hole
│   │  [SHT30]    │   │  SHT30 sits flush with top surface
│   │  fits here  │   │  ventilation slots face up (room air)
│   └─────────────┘   │
└─────────────────────┘
```

The SHT30 casing drops in from the top and is held by friction or a small lip (0.5mm).
Wires pass through inside the enclosure to the NodeMCU.

---

## Back Face Layout

```
         70mm
┌─────────────────────┐
│                     │
│   ●             ●   │  2x mounting holes, 4mm diameter
│  (15mm from      )  │  50mm center-to-center (horizontal)
│  (each side)     )  │  40mm from top
│                     │
│                     │
│                     │
└─────────────────────┘
```

**Mounting holes:** 4mm diameter, countersunk, for M3 screws into wall anchors.
**Alternative:** Keyhole slots (hang on screws already in wall, no tools needed to remove).

---

## Internal Layout

```
Side view (cross section):
       Front                Back
         │                   │
         │  [OLED]           │
         │   ──────────────  │
         │                   │
         │  [NodeMCU PCB]    │
         │  ─────────────    │   ← NodeMCU sits on 3mm standoffs
         │                   │
         └───────────────────┘
                bottom
                  │
               USB slot
```

**NodeMCU standoffs:** 3mm tall, 4 posts (one at each mounting hole of NodeMCU PCB).
**OLED mount:** Small shelf or 4 posts at front, 2mm behind front wall.
**TTP223:** Glued to back of touch hole with a small platform.
**Wire routing:** 5mm channel along bottom inside for I2C + touch wires.

---

## Tolerances

| Feature | Tolerance |
|---|---|
| OLED window | +0.3mm on all sides |
| SHT30 slot | +0.4mm on all sides (slight friction fit) |
| USB slot | +1mm W, +0.5mm H |
| Touch hole | +0.2mm radius |
| Mounting holes | exact 4.2mm (M3 clearance) |

---

## Assembly Order

1. Insert NodeMCU onto standoffs
2. Connect all wires (SDA/SCL/touch/power) before closing
3. Press OLED into front window shelf from inside
4. Insert TTP223 into touch platform from inside
5. Route SHT30 wires through internal channel
6. Drop SHT30 casing into top slot from above
7. Close lid (snap fit or 2x M2 screws on sides)

---

## 3D Model — Tools

Recommended software to create the STL:

| Tool | Cost | Difficulty | Notes |
|---|---|---|---|
| **TinkerCAD** | Free (browser) | Easy | Ideal for this box — drag and drop |
| **OpenSCAD** | Free (desktop) | Medium | Code-based, parametric — Claude can write it |
| **FreeCAD** | Free (desktop) | Hard | Full CAD, overkill for a simple box |
| **Fusion 360** | Free (personal) | Medium | Professional, good for complex shapes |

**Recommendation:** OpenSCAD — Claude Code can write the `.scad` file directly from this spec.

---

## Print Settings (recommended)

| Parameter | Value |
|---|---|
| Layer height | 0.2mm |
| Infill | 20% |
| Walls | 3 perimeters |
| Support | None needed (design to avoid overhangs) |
| Material | PLA |
| Estimated weight | ~30–40g per unit |
| Estimated print time | ~2–3h per unit |

---

## Print Services (Orlando, FL)

| Service | Type | Est. Cost | Turnaround |
|---|---|---|---|
| **Orange County Library** | Local, free/cheap | $1–3 | Same week (book slot) |
| **Treatstock.com** | Local network USA | $8–15 per unit | 3–7 days |
| **JLCPCB.com** | Online (China) | $3–5 per unit + shipping | 10–15 days |
| **Craftcloud3d.com** | Price comparison | varies | varies |

**Recommended for first iteration:** Orange County Library or Treatstock (fast turnaround to test fit).
**For final version:** JLCPCB if the design is confirmed (cheapest per unit).

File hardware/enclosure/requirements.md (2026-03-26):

# Enclosure Requirements — SniperStation Outdoor Unit

**Environment:** Outdoors, Orlando FL — full sun exposure possible, rain, humidity, temperature extremes

---

## Protection Requirements

| Parameter | Minimum | Notes |
|---|---|---|
| IP rating | IP65 | Dust-tight + protected against water jets |
| Operating temp (ambient) | 0–55°C | M5Stack Station-485 max internal is 60°C |
| UV resistance | Yes | Plastic degrades quickly in Florida sun |
| Mounting | Wall or pole mount | Near planters, avoid direct sun on enclosure |

---

## Internal Dimensions (minimum)

| Dimension | Minimum |
|---|---|
| Length | 150mm |
| Width | 120mm |
| Height | 80mm |

**Rationale:** Station-485 footprint is 54 x 54mm. Relay modules x2 add ~30mm. Wiring and connectors need ~40mm clearance.

---

## Ventilation

The Station-485 ESP32 generates heat. In a sealed enclosure under Florida summer sun, internal temperatures can exceed 60°C (controller max rating).

**Mandatory:** At least one of these ventilation strategies:

1. **Passive ventilation:** Enclosure with louvers/slots on bottom and top (chimney effect). Slots must be baffled to prevent water ingress (IP65 compatible louvers).
2. **Active ventilation:** Small 5V fan (available in SunFounder kit) with filtered intake. Fan controlled by a thermistor — activate above 45°C internal.

**Recommended:** Install in **permanent shade** (north-facing wall, under eave, or in a shaded spot). This is the single most effective thermal management measure.

---

## Cable Entry Points

Required penetrations through enclosure walls:

| Entry | Cable/Pipe | Gland Type |
|---|---|---|
| Power | 12V DC barrel jack cable | PG7 cable gland |
| Grove A1 | BH1750 sensor | PG7 cable gland |
| Grove A2 | SHT30 outdoor | PG7 cable gland |
| Grove B1 | Earth Sensor 1 | PG7 cable gland |
| Grove B2 | Earth Sensor 2 | PG7 cable gland |
| Relay C1 | Pump 1 cable | PG9 cable gland |
| Relay C2 | Pump 2 cable | PG9 cable gland |
| XKC-Y25 | Water level sensor | PG7 cable gland |
| USB-A | XKC-Y25 VCC (5V) | Internal routing if possible |

**Recommended:** Waterproof cable glands on all entries. Seal with silicone after routing.

---

## Mounting Considerations

- Mount **away from direct sun** — north or east-facing, under eave preferred
- Mount **above ground level** — minimum 30cm to avoid splash water
- Ensure drain holes or weep holes at the bottom of the enclosure to prevent water accumulation if moisture enters
- Consider cable routing — Grove cables max length ~50cm, place enclosure **close to planters**

---

## Heat Management Notes

Measured worst-case scenario for Orlando, FL:
- Ambient outdoor temp: 38°C (summer peak)
- Direct sun on metal enclosure: surface temp can reach 70–80°C
- Inside a closed enclosure in direct sun: up to 90°C possible

**Operating envelope of components:**

| Component | Max Rated Temp |
|---|---|
| Station-485 (ESP32) | 60°C |
| SHT30 | 125°C |
| BH1750 | 85°C |
| Earth Sensors | 85°C |
| M5Stack Relay | 85°C |

**Action required:** Place in shade. If shade is not possible, add forced ventilation fan.

---

## Recommended Products (Amazon search terms)

- "IP65 weatherproof enclosure 150x120x80mm"
- "waterproof junction box with ventilation"
- "PG7 cable gland waterproof" (pack of 10)
- "PG9 cable gland waterproof" (pack of 10)

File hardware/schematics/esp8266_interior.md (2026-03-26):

# ESP8266 NodeMCU — Indoor Units Wiring

**Units:** 2 identical units — Master Bedroom + Kids Bedroom
**Controller:** ESP8266 NodeMCU v3 CP2102
**Purpose:** Read indoor temp/humidity, display on OLED, publish to MQTT over WiFi
**Power:** USB 5V (from USB charger)

---

## Components per Unit

| Component | Model | I2C Address | Interface |
|---|---|---|---|
| Temp/humidity sensor | SHT30 IOT-TH02 | 0x44 | I2C |
| OLED display | SSH1106 1.3" 128x64 | 0x3C | I2C |
| Touch sensor | TTP223 capacitive | — | Digital INPUT |

No I2C address conflict. ✅

---

## Wiring Diagram

```
ESP8266 NodeMCU CP2102
┌────────────────────────────────────────────────────────────┐
│                                                            │
│  3V3  ──────────────────────────────────► SHT30 VCC       │
│  3V3  ──────────────────────────────────► OLED VCC        │
│  3V3  ──────────────────────────────────► TTP223 VCC      │
│  GND  ──────────────────────────────────► SHT30 GND       │
│  GND  ──────────────────────────────────► OLED GND        │
│  GND  ──────────────────────────────────► TTP223 GND      │
│                                                            │
│  D2 (GPIO4) ──── 10KΩ pull-up to 3V3 ──► SDA bus         │
│                                           ├── SHT30 SDA   │
│                                           └── OLED SDA    │
│                                                            │
│  D1 (GPIO5) ──── 10KΩ pull-up to 3V3 ──► SCL bus         │
│                                           ├── SHT30 SCL   │
│                                           └── OLED SCL    │
│                                                            │
│  D5 (GPIO14) ───────────────────────────► TTP223 OUT      │
│                                                            │
│  USB (micro) ───────────────────────────► USB 5V power    │
└────────────────────────────────────────────────────────────┘
```

---

## SHT30 Connection

```
ESP8266 / I2C bus         SHT30 IOT-TH02 (loose wires)
──────────────────────────────────────────────────────────
3V3             ──────►  Red    (VCC)
GND             ──────►  Black  (GND)
SDA bus (D2)    ──────►  White  (SDA)  ⚠️ COLORS CROSSED vs Grove standard
SCL bus (D1)    ──────►  Yellow (SCL)  ⚠️ COLORS CROSSED vs Grove standard
```

> **⚠️ SHT30 IOT-TH02 color mapping:** White = SDA, Yellow = SCL.
> Opposite of Grove HY2.0 standard. Verify before powering on.

---

## OLED SSH1106 Connection

```
ESP8266 / I2C bus         SSH1106 1.3" OLED (4-pin)
──────────────────────────────────────────────────────────
3V3             ──────►  VCC
GND             ──────►  GND
SDA bus (D2)    ──────►  SDA
SCL bus (D1)    ──────►  SCL
```

- Library: **U8g2** (`U8G2_SH1106_128X64_NONAME_F_HW_I2C`)
- I2C address: 0x3C

---

## TTP223 Touch Sensor Connection

```
ESP8266                   TTP223
──────────────────────────────────────────────────────────
3V3             ──────►  VCC
GND             ──────►  GND
D5 (GPIO14)     ──────►  OUT  (HIGH on touch)
```

- Configured as INPUT in firmware
- Triggers display wake from screensaver

---

## I2C Pull-up Resistors

External 10KΩ pull-ups required on both SDA and SCL (ESP8266 internal pull-ups insufficient for reliable I2C with two devices).

```
3V3 ──── 10KΩ ──── D2 (SDA bus)
3V3 ──── 10KΩ ──── D1 (SCL bus)
```

---

## GPIO Summary

| GPIO | NodeMCU Label | Function | Direction |
|---|---|---|---|
| GPIO4 | D2 | I2C SDA — SHT30 + OLED | I/O |
| GPIO5 | D1 | I2C SCL — SHT30 + OLED | I/O |
| GPIO14 | D5 | TTP223 touch signal | INPUT |

---

## Display Behavior & Brightness Logic

| State | Trigger | Brightness | Content |
|---|---|---|---|
| Screensaver | Default / 30s timeout | 10/255 | SniperStation logo (bitmap) |
| Active | Touch detected | 200/255 | Temp + humidity + date + time |
| Night mode | 00:00 – 06:00 (NTP) | 0 (display off) | — |

**State machine:**
```
SCREENSAVER ──── touch ────► ACTIVE (30s timer starts)
   ▲                              │
   └──────── timeout / night ─────┘
```

Brightness controlled via U8g2 `setContrast()` (maps to SSH1106 register 0x81, 0–255).

---

## OLED Layout — Active Mode (128x64)

```
┌────────────────────────────┐
│ [SS] SniperStation           │  ← small logo 16x16 + title (line 1)
│ ──────────────────────── │  ← separator
│  25.3°C        72% RH      │  ← sensor data (line 3)
│  Mar 25, 2026  14:23       │  ← NTP date + time (line 4)
└────────────────────────────┘
```

## OLED Layout — Screensaver Mode (128x64)

```
┌────────────────────────────┐
│                            │
│      [LOGO 48x48]          │  ← centered large bitmap
│      SniperStation           │  ← centered name below logo
│                            │
└────────────────────────────┘
```

---

## Date / Time — NTP

No RTC hardware needed. Time synced via WiFi on boot and every hour.

- Server: `pool.ntp.org`
- Timezone: `America/New_York` (Orlando, FL — UTC-5 / UTC-4 DST)
- Library: `NTPClient` + `ESP8266WiFi`
- Fallback if WiFi lost: display last known time + `(no sync)` indicator

---

## MQTT Topics

### Master Bedroom unit (`ROOM_ID = "master"`)

| Topic | Value | Frequency |
|---|---|---|
| `sniperstation/interior/master/temperatura` | float (°C) | Every 60s |
| `sniperstation/interior/master/humedad` | float (%) | Every 60s |

### Kids Bedroom unit (`ROOM_ID = "kids"`)

| Topic | Value | Frequency |
|---|---|---|
| `sniperstation/interior/kids/temperatura` | float (°C) | Every 60s |
| `sniperstation/interior/kids/humedad` | float (%) | Every 60s |

Firmware is identical for both units. Only `ROOM_ID` differs.

---

## Physical Enclosure

Custom 3D printed enclosure (same design for both units). Contains:
- ESP8266 NodeMCU (49 x 26mm)
- OLED 1.3" SSH1106 — front face cutout/window
- TTP223 touch sensor — front face, finger accessible
- SHT30 — top of enclosure, casing exposed to room air

See `hardware/enclosure/indoor_unit_design.md` for full specs (pending).

---

## Power Note

- Power via micro-USB (5V USB charger)
- SHT30 and OLED powered from 3V3 pin only
- Do **not** power SHT30 from 5V on this unit

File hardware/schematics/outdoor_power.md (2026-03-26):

# Outdoor Power Distribution — SniperStation

**Power source:** 12V 2A DC adapter (5.5×2.1mm barrel jack)
**Total load:** ≤400mA @ 12V worst case (safety margin 5×)

---

## Power Tree

```
┌─────────────────────────────────────────────────────────────────┐
│           12V 2A DC ADAPTER (5.5×2.1mm barrel)                  │
│                         │                                        │
│               ┌─────────┘                                        │
│               │                                                   │
│               ▼                                                   │
│      ┌─────────────────┐   ┌─────────────────┐                  │
│      │  Wago 221-415   │   │  Wago 221-415   │                  │
│      │   +12V RAIL     │   │    GND RAIL     │                  │
│      │                 │   │                 │                  │
│      │ IN:  Adapter +  │   │ IN:  Adapter -  │                  │
│      │ OUT1: Station ──┤   ├── Station-485 - │                  │
│      │ OUT2: Relay1 COM┤   ├── Pump 1 (-)   │                  │
│      │ OUT3: Relay2 COM┤   ├── Pump 2 (-)   │                  │
│      │ OUT4: Buck IN + ┤   ├── Buck IN -    │                  │
│      └─────────────────┘   └─────────────────┘                  │
│               │                                                   │
│       ┌───────┼───────────────────────────┐                      │
│       │       │                           │                      │
│       ▼       ▼                           ▼                      │
│  ┌─────────────────┐            ┌──────────────────┐            │
│  │  Station-485    │            │ 12V→5V Buck Conv │            │
│  │  9–24V PWR485   │            │ (LM2596/MP1584)  │            │
│  │                 │            │                  │            │
│  │  5V internal ───┼──► Grove   │  5V out ─────────┼──► TimerCam X (USB-C)  │
│  │                 │    ├── BH1750  (~1mA)          │    active: ~180mA      │
│  │                 │    ├── SHT30   (~1mA)          │    sleep:  ~0.001mA    │
│  │                 │    ├── Earth×2 (~5mA each)     └──────────────────┘    │
│  │                 │    └── Relays  (~70mA active)                           │
│  │  USB-A 5V ──────┼──► XKC-Y25 + driver (~10mA)                           │
│  │                 │                                                          │
│  │  Relay 1 NO ────┼──► Pump SucuFer + (~80mA)                             │
│  │  Relay 2 NO ────┼──► Pump SucuRod + (~80mA, never simultaneous)         │
│  └─────────────────┘                                                         │
└─────────────────────────────────────────────────────────────────────────────┘
```

---

## Why a Separate Buck Converter for TimerCam X

The Station-485 USB-A output is already used by the XKC-Y25 driver board.
Adding the TimerCam X to the same USB-A port risks instability when the camera
wakes up and draws ~180mA.

**Solution:** A dedicated 12V→5V mini buck converter for the TimerCam X.

**Recommended part:** Mini DC-DC step-down module (LM2596 or MP1584)
- Input: 12V
- Output: 5V fixed
- Max current: 2A (well above TimerCam's 180mA peak)
- Cost: ~$1–3 on Amazon
- Physical: ~23×17mm — fits easily in the IP65 enclosure

---

## Power Budget (Outdoor)

| Component | Voltage | Current (idle) | Current (peak) | Notes |
|---|---|---|---|---|
| Station-485 | 12V | 120mA | 200mA | WiFi active = 161mA |
| Pump SucuFer | 12V | 0 | 100mA | via Relay 1 — never simultaneous with Pump 2 |
| Pump SucuRod | 12V | 0 | 100mA | via Relay 2 — never simultaneous with Pump 1 |
| BH1750 | 5V (internal) | 0.2mA | 0.2mA | negligible |
| SHT30 outdoor | 5V (internal) | 0.8mA | 0.8mA | negligible |
| Earth Sensor ×2 | 5V (internal) | 5mA each | 5mA each | |
| XKC-Y25 + driver | 5V USB-A | 10mA | 10mA | Station-485 USB-A |
| Relay ×2 | 5V (internal) | ~0mA | 70mA each | only when pump active |
| TimerCam X | 5V (buck) | 0.001mA | 180mA | sleep 2µA, active ~180mA |
| **TOTAL WORST CASE** | **12V** | | **~380mA** | Station-485 WiFi + 1 pump active |

**Adapter rating:** 12V 2A = 2000mA
**Worst case draw:** ~380mA
**Safety margin: 5×** ✅

> Worst case: Station-485 WiFi active (161mA) + 1 pump (80mA) + TimerCam active (180mA) ≈ **421mA**
> Still well within 2A capacity. ✅

---

## Protection Components

| Component | Value | Location | Purpose |
|---|---|---|---|
| Diode 1N4007 | — | Across each pump terminals | Flyback protection (inductive load) |
| Capacitor electrolytic | 10µF | Near relay outputs | Power supply noise filter |

---

## Wiring Notes

- All outdoor connections inside IP65 enclosure
- Cable glands required for: 12V power in, Grove cables to sensors, tubing out, TimerCam X power
- TimerCam X mounts on enclosure wall with acrylic/glass window for lens
- USB-C cable from buck converter to TimerCam X — keep short (≤30cm inside enclosure)

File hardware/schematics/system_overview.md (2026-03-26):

# System Overview — SniperStation

```
┌─────────────────────────────────────────────────────────────────────────────┐
│                              OUTDOOR UNIT                                   │
│                                                                             │
│  ┌─────────────────────────────────────────────────────┐                   │
│  │               M5Stack Station-485                    │                   │
│  │                    (ESP32)                           │                   │
│  │                                                      │                   │
│  │  Port A1 ──── BH1750 (Light, I2C 0x23)             │                   │
│  │  Port A2 ──── SHT30 outdoor (Temp/Hum, I2C 0x44)   │                   │
│  │  Port B1 ──── Earth Sensor 1 (SucuFer, Analog)     │                   │
│  │  Port B2 ──── Earth Sensor 2 (SucuRod, Analog)     │                   │
│  │  Port C1 ──── Relay 1 ──── Pump 1 (SucuFer)        │                   │
│  │  Port C2 ──── Relay 2 ──── Pump 2 (SucuRod)        │                   │
│  │  GPIO  ────── XKC-Y25 (Water level, Digital)        │                   │
│  │                                                      │                   │
│  │  PWR485 ───── 12V 2A DC Adapter                     │                   │
│  │  WiFi ──────────────────────────────────────────────┼──► MQTT Broker   │
│  └─────────────────────────────────────────────────────┘                   │
│                                                                             │
│  ┌──────────┐  ┌──────────┐  ┌─────────────────┐  ┌──────────────────┐    │
│  │ Pump 1   │  │ Pump 2   │  │ XKC-Y25 Sensor  │  │ TimerCam X       │    │
│  │ 12V 80mA │  │ 12V 80mA │  │ + DFRobot driver│  │ OV3660 3MP       │    │
│  │ → SucuFer│  │ → SucuRod│  │ Water reservoir │  │ ESP32 + battery  │    │
│  │          │  │          │  │ (non-contact)   │  │ WiFi → HTTP/MQTT │    │
│  │ FOV 66.5°        │    │
│  │ sleep: 2µA       │    │
│  └──────────┘  └──────────┘  └─────────────────┘  └──────────────────┘    │
└─────────────────────────────────────────────────────────────────────────────┘

┌─────────────────────────────────────────────────────────────────────────────┐
│                         INDOOR UNIT — MASTER BEDROOM                        │
│                                                                             │
│  ┌─────────────────────────────────────────────────────┐                   │
│  │          CYD ESP32-2432S028  (ROOM_ID=master)        │                   │
│  │                                                      │                   │
│  │  CN1 GPIO21 ── I2C SDA ── SHT30 (0x44)              │                   │
│  │  CN1 GPIO22 ── I2C SCL ── SHT30 (0x44)              │                   │
│  │  10KΩ pull-ups on SDA + SCL                         │                   │
│  │                                                      │                   │
│  │  [TFT 2.8" 240x320 color] — integrated              │                   │
│  │  [XPT2046 resistive touch] — integrated             │                   │
│  │  [SHT30 cased] ────────── top of enclosure, exposed │                   │
│  │                                                      │                   │
│  │  WiFi ──────────────────────────────────────────────┼──► MQTT Broker   │
│  └─────────────────────────────────────────────────────┘                   │
└─────────────────────────────────────────────────────────────────────────────┘

┌─────────────────────────────────────────────────────────────────────────────┐
│                         INDOOR UNIT — KIDS BEDROOM                          │
│                                                                             │
│  ┌─────────────────────────────────────────────────────┐                   │
│  │          CYD ESP32-2432S028  (ROOM_ID=kids)          │                   │
│  │                                                      │                   │
│  │  CN1 GPIO21 ── I2C SDA ── SHT30 (0x44)              │                   │
│  │  CN1 GPIO22 ── I2C SCL ── SHT30 (0x44)              │                   │
│  │  10KΩ pull-ups on SDA + SCL                         │                   │
│  │                                                      │                   │
│  │  [TFT 2.8" 240x320 color] — integrated              │                   │
│  │  [XPT2046 resistive touch] — integrated             │                   │
│  │  [SHT30 cased] ────────── top of enclosure, exposed │                   │
│  │                                                      │                   │
│  │  WiFi ──────────────────────────────────────────────┼──► MQTT Broker   │
│  └─────────────────────────────────────────────────────┘                   │
└─────────────────────────────────────────────────────────────────────────────┘

┌─────────────────────────────────────────────────────────────────────────────┐
│                         PROXMOX LXC (Server)                                │
│                                                                             │
│  ┌──────────────┐  ┌──────────────┐  ┌──────────┐  ┌──────────────────┐   │
│  │  Mosquitto   │  │  InfluxDB    │  │ Grafana  │  │  Telegram Bot    │   │
│  │  MQTT Broker │→ │  2.x         │→ │  :3000   │  │  (Python)        │   │
│  │  :1883       │  │  :8086       │  │          │  │                  │   │
│  └──────────────┘  └──────────────┘  └──────────┘  └──────────────────┘   │
│         ▲                                                    ▲              │
│         │                                                    │              │
│    MQTT data from                                    Alerts + commands      │
│    Station-485 + ESP8266                             from/to user phone     │
└─────────────────────────────────────────────────────────────────────────────┘
```

## Data Flow

```
Sensor read (Station-485)
    │
    ├── Every 60 seconds: publish sensor data to MQTT topics
    │
    ├── Every 6 hours: evaluate irrigation logic
    │       │
    │       ├── soil_moisture < 30% AND air_humidity < 85% AND water_available
    │       │       └── activate pump (20s) → wait 30min → re-check
    │       │
    │       └── condition not met → skip
    │
    └── Threshold breach → publish alert topic → Telegram Bot → user phone

Sensor read (CYD ESP32 indoor)
    │
    └── Every 60 seconds: publish indoor temp/hum to MQTT topics

TimerCam X (outdoor, deep sleep cycle)
    │
    ├── RTC wakes camera every 4h (configurable)
    ├── Takes photo → HTTP POST → Proxmox LXC storage
    ├── Publishes MQTT event → Grafana panel refreshes
    └── Returns to deep sleep (~2µA)

MQTT → Telegraf/Bridge → InfluxDB → Grafana panels
```

## MQTT Topic Schema

| Topic | Direction | Type | Published by |
|---|---|---|---|
| `sniperstation/exterior/temperatura` | OUT | float (°C) | Station-485 |
| `sniperstation/exterior/humedad` | OUT | float (%) | Station-485 |
| `sniperstation/exterior/luz` | OUT | int (lx) | Station-485 |
| `sniperstation/interior/master/temperatura` | OUT | float (°C) | ESP8266 master |
| `sniperstation/interior/master/humedad` | OUT | float (%) | ESP8266 master |
| `sniperstation/interior/kids/temperatura` | OUT | float (°C) | ESP8266 kids |
| `sniperstation/interior/kids/humedad` | OUT | float (%) | ESP8266 kids |
| `sniperstation/sucufer/humedad_suelo` | OUT | float (%) | Station-485 |
| `sniperstation/sucurod/humedad_suelo` | OUT | float (%) | Station-485 |
| `sniperstation/sucufer/bomba` | OUT | int (0/1) | Station-485 |
| `sniperstation/sucurod/bomba` | OUT | int (0/1) | Station-485 |
| `sniperstation/sucufer/bomba/set` | IN | int (0/1) | Telegram Bot |
| `sniperstation/sucurod/bomba/set` | IN | int (0/1) | Telegram Bot |
| `sniperstation/agua/nivel` | OUT | int (0/1) | Station-485 |
| `sniperstation/sistema/estado` | OUT | string (JSON) | Station-485 |
| `sniperstation/alertas` | OUT | string (JSON) | Station-485 |
| `sniperstation/camaras/sucufer/captura` | OUT | string (filename) | TimerCam X |
| `sniperstation/camaras/sucurod/captura` | OUT | string (filename) | TimerCam X (2nd unit, future) |

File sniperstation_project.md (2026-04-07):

# SniperStation — Complete Project

> Context document for Claude Code
> Generated from planning session in Claude.ai

---

## Project Description

Automatic irrigation + weather station system for two succulent planters located **outdoors** at a home in **Orlando, Florida**. The system monitors environmental conditions (temperature, humidity, sunlight, soil moisture) and automatically irrigates based on sensors, with a web dashboard, Telegram alerts, and historical data.

---

## System Architecture

```
[OUTDOORS]                                  [INDOORS]
Station-485 (main brain)                    CYD ESP32-2432S028
├── DLight BH1750    → Port A1              ├── SHT30 master bedroom
├── SHT30 exterior   → Port A2             └── SHT30 kids bedroom
├── Earth Sensor 1   → Port B1                  │
├── Earth Sensor 2   → Port B2                  │
├── Relay Pump 1     → Port C1                  │
├── Relay Pump 2     → Port C2                  │
└── Water Level      → GPIO                     │
     (XKC-Y25)                                  │
          │                                     │
          └──────── WiFi → MQTT ────────────────┘
                         │
                  [Proxmox LXC]
                  ├── Mosquitto (MQTT broker)
                  ├── InfluxDB (time-series database)
                  ├── Grafana (web / mobile dashboard)
                  └── Telegram Bot (alerts + NL agent)
```

---

## Complete Hardware List

### Confirmed / purchased

| Component | Model | Details | Source |
|---|---|---|---|
| Main controller | M5Stack Station-485 | ESP32, WiFi, 1.14" display, 6x Grove, RS485, 9-24V input | In hand |
| Light sensor | DLight BH1750 | I2C (0x23), 1-65535 lx, Grove HY2.0 | In hand |
| Temp/hum sensor x2 | SHT30 IOT-TH02 | I2C (0x44), 2.15-5.5V, color-coded loose wires | Amazon ✅ |
| Grove↔Dupont cable | HY2.0-4P to 2.54mm female | To connect SHT30 to Station-485 Grove ports | Amazon ✅ |
| Peristaltic pumps x2 | DC 12-24V | 0-100 ml/min, 80mA, reversible, with tubing | Amazon ✅ |
| Water level sensor | XKC-Y25-V + DFRobot driver | Non-contact, 5-24V, digital output, 4 sensitivity levels | Amazon ✅ |
| Soil moisture sensor x2 | M5Stack Earth Sensor | Analog + digital, Grove HY2.0 | M5Stack ✅ |
| Relay x2 | M5Stack Mini 3A Relay | 3A/30VDC, GPIO control, Grove HY2.0 | M5Stack ✅ |
| Indoor unit (all-in-one) | ESP32-2432S028 CYD x2 | ESP32 + 2.8" TFT 240x320 + touch + I2C SHT30 | Amazon ✅ |
| Timelapse camera | M5Stack ESP32 PSRAM Timer Camera X (OV3660) | 3MP, FOV 66.5°, WiFi, RTC, battery, sleep 2µA | M5Stack ✅ |

### Pending purchase (Amazon)

| Component | Specification | Notes |
|---|---|---|
| DC adapter | 12V 2A, 5.5mm connector | Powers Station-485 + pumps |
| Outdoor enclosure | Weatherproof with ventilation | Must handle Orlando summer heat (max 60°C) |

---

## Connections / Pinout

### Station-485 — Grove Ports

| Port | Sensor/Actuator | Protocol | Notes |
|---|---|---|---|
| A1 | DLight BH1750 | I2C (0x23) | Shared bus with A2 |
| A2 | SHT30 exterior | I2C (0x44) | Shared bus with A1 — no conflict |
| B1 | Earth Sensor SucuFer | Analog | G25/G35 |
| B2 | Earth Sensor SucuRod | Analog | G26/G36 ⚠️ G36 cannot be OUTPUT |
| C1 | Relay → Pump 1 | Digital OUTPUT | G14 |
| C2 | Relay → Pump 2 | Digital OUTPUT | G17 |
| USB-A output | XKC-Y25 sensor (VCC) | 5V power only | No signal |
| Free B or C | XKC-Y25 signal OUT | Digital INPUT | Confirm available port |

### SHT30 — Connection to Grove↔Dupont cable

```
Grove cable (Station-485)    →    SHT30 (loose wires)
Red    (5V)                  →    Red    (VCC)
Black  (GND)                 →    Black  (GND)
Yellow (SDA)                 →    White  (SDA) ⚠️ COLORS CROSSED
White  (SCL)                 →    Yellow (SCL) ⚠️ COLORS CROSSED
```

### Peristaltic pumps — Power

```
12V 2A Adapter
├── PWR485 → powers Station-485
├── Relay C1 (NO) → Pump 1 (+12V red)
└── Relay C2 (NO) → Pump 2 (+12V red)
Common GND shared across everything
```

### Water level sensor XKC-Y25-V

```
DFRobot Driver    →    Station-485
VCC               →    5V (USB-A output or Grove)
GND               →    GND
OUT               →    GPIO digital INPUT
```
- Attached to the **outside** of the plastic container
- 4 sensitivity levels with SET button
- HIGH = water present, LOW = empty container

### CYD ESP32 (indoor) — SHT30 indoor

```
CYD CN1 GPIO21   →    SHT30 SDA
CYD CN1 GPIO22   →    SHT30 SCL
10KΩ pull-up resistors on SDA and SCL
```

---

## Power Budget

| Component | Voltage | Current |
|---|---|---|
| Station-485 (normal operation) | 12V | ~161mA |
| Pump 1 (active) | 12V | 80mA |
| Pump 2 (active) | 12V | 80mA |
| Grove sensors | 5V | ~20mA total |
| **Maximum total** | **12V** | **~341mA** |

Recommended adapter: **12V 2A** (ample safety margin)

---

## Irrigation Logic

### Rules for succulents (very sensitive to overwatering)

```
Every 6 hours (via RTC BM8563):
  IF soil_moisture < dry_threshold:
    IF air_humidity < 85% (not raining):
      IF water_available == TRUE:
        activate_pump(planter, 20 seconds)  // ~33ml at 100ml/min
        wait 30 minutes
        read soil_moisture again
        IF still_dry: send Telegram alert
      ELSE:
        send Telegram alert "Empty water container"
```

### Reference flow rate (12V peristaltic pump)
- Maximum speed: ~100 ml/min = 1.67 ml/second
- 10 seconds = ~17 ml (gentle irrigation)
- 20 seconds = ~33 ml (normal succulent irrigation)
- 30 seconds = ~50 ml (heavy irrigation — avoid)

### Suggested thresholds (calibrate with Earth Sensor)
- Dry soil: < 30% moisture → irrigate
- Moist soil: 30-60% → do not irrigate
- Wet soil: > 60% → excess moisture alert

---

## Software Stack (Proxmox LXC)

### Services to install

| Service | Port | Function |
|---|---|---|
| Mosquitto | 1883 | MQTT broker — receives data from Station-485 and CYDs |
| InfluxDB 2.x | 8086 | Time-series database |
| Grafana | 3000 | Responsive web dashboard (mobile) |
| Telegram Bot | — | Automatic push alerts + NL agent |

### MQTT Topics

```
sniperstation/exterior/temperatura
sniperstation/exterior/humedad
sniperstation/exterior/luz
sniperstation/interior/master/temperatura
sniperstation/interior/master/humedad
sniperstation/interior/kids/temperatura
sniperstation/interior/kids/humedad
sniperstation/sucufer/humedad_suelo
sniperstation/sucurod/humedad_suelo
sniperstation/sucufer/bomba (0/1)
sniperstation/sucurod/bomba (0/1)
sniperstation/agua/nivel (0/1)
sniperstation/sistema/estado
```

### Telegram Alerts
- Irrigation executed (planter + ml delivered)
- Empty water container
- Soil very dry for more than 24h
- Exterior temperature > 38°C (extreme Orlando heat)
- Sensor disconnected / reading error

---

## Grafana Dashboard — Suggested Panels

1. **Exterior vs interior temperature** — timeline, last 24h
2. **Exterior vs interior humidity** — timeline
3. **Sunlight (lux)** — area, last 24h
4. **Soil moisture SucuFer and SucuRod** — gauge + history
5. **Recent irrigations** — table with timestamp and ml
6. **Water container level** — ON/OFF indicator
7. **Weekly summary** — temp min/max, total irrigations

---

## Important Considerations

### Orlando Heat
- Station-485 maximum temperature: **0~60°C**
- Orlando summer outdoors in direct sun: easily exceeds 60°C inside a closed box
- **Mandatory:** enclosure in **shade** + passive or active ventilation
- Consider a small 5V fan inside the box if needed

### Station-485 Port B2
- Uses GPIO G36 of ESP32
- G36 **CANNOT be configured as OUTPUT** on ESP32
- Earth Sensor 2 can only be INPUT (analog reading) — correct for this use
- Relays must NOT be connected to port B

### Shared I2C A1/A2
- DLight (0x23) and SHT30 (0x44) have different addresses → no conflict
- Both on the same I2C bus (G32/G33)

### Reversible pump
- Inverting polarity inverts flow direction
- Useful feature: drain tubing after irrigation to prevent residual moisture
- Implementable with double relay or H-bridge (L293D available in SunFounder kit)

---

## Complete Available Inventory

### Main Microcontrollers and Modules

| Component | Qty | Specifications | Potential Use |
|---|---|---|---|
| ESP8266 NodeMCU CP2102 | 2 | WiFi, ESP-12E, Arduino IDE/MicroPython compatible | Freed up — future projects |
| M5Stack Station-485 | 1 | ESP32, WiFi, RS485, 6x Grove, 1.14" display | SniperStation main brain |
| DLight BH1750 | 1 | I2C light sensor, 1-65535 lx, Grove | SniperStation exterior |

---

### SunFounder Raphael Ultimate Kit (337 pieces) — Detailed Inventory

#### Modules and Sensors
| Component | Qty | Specifications | Potential Use |
|---|---|---|---|
| I2C LCD 1602 | 1 | 16x2 display, I2C | Secondary display / status |
| Ultrasonic Ranging Module | 1 | HC-SR04, 2cm-400cm | Distance sensor / alternative water level |
| Dot Matrix Module | 1 | 8x8 LEDs | Animation display |
| Breadboard Power Module | 1 | 5V/3.3V | Prototype power supply |
| Rotary Encoder Module | 1 | — | Manual parameter control |
| Joystick | 1 | Analog X/Y + button | Menu navigation |
| MFRC522 RFID Module | 1 | 13.56MHz | Access control / authentication |
| Infrared Motion Sensor | 1 | PIR AS312 | Presence detection |
| Motor (DC) | 1 | — | Generic actuator |
| 9G Servo | 1 | SG90 | Valve control / movement |
| 4-Digit 7-segment Display | 1 | — | Numeric display |
| Keypad | 1 | 4x4 matrix | Data entry / PIN |
| Reed Switch Module | 1 | Magnetic | Box opening detection |
| Obstacle Avoidance Module | 1 | IR reflective | Proximity detection |
| Speed Sensor Module | 1 | LM393 + slot | Speed encoder / flow |
| Temperature and Humidity Sensor | 1 | DHT11 or DHT22 | Backup temp/hum sensor |
| MPU6050 Module | 1 | Accelerometer + gyroscope I2C | Motion / vibration detection |
| Audio Power Amplifier Module | 1 | — | Audio alerts |
| Touch Sensor Module | 1 | Capacitive | Manual irrigation touch button |
| Fan | 1 | 5V DC | Station-485 box ventilation if needed |
| LED Bar Graph | 1 | 10 segments | Visual water level indicator |
| Relay Module | 1 | 5V, 1 channel | Spare relay / future projects |
| Camera Module | 1 | For Raspberry Pi | Surveillance / plant timelapse |
| Speaker | 1 | — | Audio alerts |

#### Passive and Discrete Components
| Component | Qty | Value | Potential Use |
|---|---|---|---|
| Resistor | 10 | 10Ω | LED current limiting |
| Resistor | 10 | 100Ω | Current limiting |
| Resistor | 10 | 220Ω | Standard LEDs |
| Resistor | 10 | 330Ω | LEDs / voltage divider |
| Resistor | 10 | 1KΩ | Transistor base |
| Resistor | 10 | 2KΩ | Voltage dividers |
| Resistor | 10 | 5.1KΩ | Pull-down |
| Resistor | 10 | 10KΩ | I2C pull-up (CYD + ESP8266) |
| Resistor | 10 | 100KΩ | High impedance pull-down |
| Resistor | 10 | 1MΩ | High impedance |
| Zener Diode | 2 | — | Voltage regulation |
| 1N4007 Diode | 2 | — | Flyback protection for pumps |
| S8550 Transistor PNP | 5 | — | PNP switching |
| S8050 Transistor NPN | 5 | — | Load current control |
| Thermistor | 1 | NTC | Backup analog temperature |
| Electrolytic Capacitor | 5 | 10uF | Pump noise filtering |
| Ceramic Capacitor | 20 | 104/103 | Power supply decoupling |
| Photoresistor (LDR) | 1 | — | Backup analog light sensor |

#### Switches and Controls
| Component | Qty | Type | Potential Use |
|---|---|---|---|
| Button | 1 | Pushbutton | Reset / manual action |
| Potentiometer | 3 | — | Analog threshold adjustment |
| Micro Switch | 2 | — | End stop |
| Button Switch | 10 | Small pushbutton | Multiple interfaces |
| Slide Switch | 2 | — | Manual ON/OFF |
| Tilt Switch | 1 | — | Tilt / fall detection |

#### LEDs and Indicators
| Component | Qty | Color | Potential Use |
|---|---|---|---|
| Green LED | 5 | Green | OK status |
| Yellow LED | 5 | Yellow | Warning |
| Blue LED | 5 | Blue | Info / active irrigation |
| Red LED | 5 | Red | Alert / error |
| White LED | 5 | White | General lighting |
| RGB LED | 1 | RGB | Multi-state indicator |

#### ICs and Special Modules
| Component | Qty | Description | Potential Use |
|---|---|---|---|
| MCP3008 | 1 | 8-channel SPI ADC | More analog inputs |
| L293D | 1 | H-Bridge motor driver | Reversible pump (drain tubing) |
| 74HC595 | 2 | 8-bit shift register | Expand digital outputs |

#### Buzzers
| Component | Qty | Type | Potential Use |
|---|---|---|---|
| Active Buzzer | 2 | Fixed frequency | Simple audio alerts |
| Passive Buzzer | 2 | Variable frequency | Melodies / custom alerts |

#### Cables and Connectors
| Component | Qty | Type | Potential Use |
|---|---|---|---|
| Jump Wire F/M | 10 | 20cm | Prototype connections |
| Jump Wire F/F | 10 | 20cm | Module-to-module connections |
| Jump Wire M/M | 65 | 20cm | Breadboard |
| 40 Pin GPIO Cable | 1 | Raspberry Pi ribbon | GPIO expansion |
| 9V Battery Cable | 1 | — | Portable power |
| Audio Cable | 1 | — | Audio |

#### Other
| Component | Qty | Description |
|---|---|---|
| Breadboard | 1 | 830 points — ESP8266 prototyping |
| T-shape Extension Board | 1 | Raspberry Pi GPIO expansion |

---

### Additional Inventory (outside SunFounder kit)

| Component | Qty | Specifications | Potential Use |
|---|---|---|---|
| Touch Sensor Button | 2 | Capacitive, Arduino/ESP compatible | Manual touch irrigation (SniperStation) |
| ESP8266 NodeMCU CP2102 | 2 | ESP-12E, WiFi, Arduino/MicroPython | Freed up — future projects |
| IR Receiver 38kHz | 5 | Digital, Dupont cable | IR remote control projects |
| IR Transmitter 38kHz | 5 | Digital, Dupont cable | IR emitter / device control |
| KY-037 Sound Sensor | 6 | 4 pins, microphone, digital/analog output | Sound detection / noise level |

---

### Future Project Ideas with this Inventory

| Project | Required inventory components |
|---|---|
| **Succulent timelapse camera** | Camera Module + Raspberry Pi |
| **Local audio alert** when container empty | Active Buzzer + Station-485 |
| **IR remote irrigation control** | IR Receiver 38kHz + ESP8266 |
| **Automatic fan** for Station-485 box | 5V Fan + Relay + Thermistor |
| **Garden presence monitor** | PIR Motion Sensor + ESP8266 |
| **RFID lock** for outdoor enclosure | MFRC522 + ESP8266 |
| **Status display** visible from a distance | LED Bar Graph (water level) |
| **Manual control** with rotary encoder | Rotary Encoder + Station-485 |
| **Expansion to more planters** | MCP3008 (more analog inputs) + relays |
| **Reversible pump** to drain tubing | L293D H-Bridge |

---

## Design Decisions Made

1. **Peristaltic pump** over submersible → greater precision for succulents (small water amounts)
2. **One large shared container** for both pumps → simpler, less refilling
3. **Capacitive water level sensor** (XKC-Y25) → non-contact, no moving parts
4. **Station-485 outdoors** next to the planters → short cables, everything together
5. **CYD ESP32** indoors per bedroom → no cables through walls
6. **Proxmox LXC** for the software stack → infrastructure already available
7. **InfluxDB + Grafana + Mosquitto** → standard IoT stack, well documented
8. **12V 2A adapter** → powers Station-485 and pumps from a single source
9. **Generic SHT30** instead of M5Stack ENV III → out of stock, same chip

---

## Next Steps

- [ ] Buy: 12V 2A adapter, weatherproof enclosure
- [ ] Write Station-485 firmware (Arduino IDE)
- [ ] Write CYD indoor firmware (Arduino IDE + LVGL)
- [ ] Write TimerCam X firmware
- [ ] Calibrate Earth Sensors with the actual planters
- [ ] Calibrate exact pump flow rate (ml/second at 12V)
- [ ] Adjust humidity thresholds for specific succulents
- [ ] Configure Grafana dashboard (7 panels)
- [ ] Implement HTTP photo upload endpoint for TimerCam X
- [ ] Install and test in the field

---

*Document generated: March 25, 2026*
*Continue development in Claude Code using this file as context*

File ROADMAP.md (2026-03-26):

# SniperStation — Roadmap

## Phase 1 — Hardware Assembly
**Goal:** All physical components wired, powered, and verified independently before any firmware.

- [ ] Purchase remaining components: outdoor IP65 enclosure
- [ ] Redesign 3D enclosure for CYD form factor (simple wall frame) once boards arrive
- [ ] Send 3D enclosure to print x2 (master + kids bedroom)
- [ ] Wire Station-485 with all Grove sensors (BH1750, SHT30, Earth Sensors x2)
- [ ] Wire relay modules and connect peristaltic pumps
- [ ] Connect XKC-Y25 water level sensor (confirm GPIO port assignment)
- [ ] Wire CYD (master): SHT30 on CN1 connector (GPIO21/22), I2C pull-ups 10KΩ
- [ ] Wire CYD (kids): same as master
- [ ] Power-on test: verify 12V → Station-485 + pumps from single adapter
- [ ] Bench test each sensor individually (I2C scanner, analog reads)
- [ ] Bench test CYD display with TFT_eSPI (hello world + touch calibration)
- [ ] TimerCam X hardware setup
  - [ ] Test TimerCam X WiFi connection and photo capture
  - [ ] Mount in outdoor enclosure with acryllic window facing planters
  - [ ] Confirm 5V USB power supply (from Station-485 enclosure or separate)

### Security — Phase 1
> Reference: `docs/security.md` sections 1.1, 1.3, 1.4, 14.3
- [ ] Use IP65 enclosure with **Torx or hexalobe security screws** (not Phillips) — prevents casual tampering
- [ ] Install **cable glands (PG7/PG9)** for every cable exiting the outdoor enclosure — mandatory for Orlando rain
- [ ] Seal cable glands with neutral silicone after installation
- [ ] 3D enclosure for CYD must **block access to EN (reset) button** — expose screen only
- [ ] **Document MAC address of each ESP32** before installation → save to `hardware/inventory.md`

---

## Phase 2 — Firmware Development
**Goal:** Both microcontrollers reading sensors and publishing to MQTT.

- [ ] Station-485 firmware (Arduino IDE)
  - [ ] I2C sensor reads: BH1750 + SHT30
  - [ ] Analog soil moisture reads (B1, B2)
  - [ ] Digital water level read (XKC-Y25)
  - [ ] Relay control for pumps (C1, C2)
  - [ ] WiFi connection + MQTT publish
  - [ ] Irrigation logic (6h cycle, RTC BM8563)
  - [ ] MQTT subscribe for manual override commands
  - [ ] Display status on built-in 1.14" screen
- [ ] CYD ESP32-2432S028 indoor firmware — identical for both units, `ROOM_ID` configurable (Arduino IDE)
  - [ ] SHT30 I2C read via CN1 connector (GPIO21 SDA, GPIO22 SCL)
  - [ ] TFT display init via TFT_eSPI library
  - [ ] Screensaver: animated cactus logo + compact temp summary all rooms (30s timeout → dim)
  - [ ] Main view: all rooms temp/hum + exterior + soil moisture
  - [ ] Detail view: tap a plant → owner photo background + soil data + plant age since Apr 22 2024
  - [ ] Resistive touch handling (XPT2046) → navigate views
  - [ ] Bilingual EN/ES — per device, stored in NVS flash, default EN
  - [ ] All UI strings in `strings.h` as `STR_xxx[2]` arrays indexed by `lang` (0=EN, 1=ES)
  - [ ] Adaptive brightness: active 255, screensaver 30, night 00–06h off
  - [ ] WiFi connection + NTP time sync (pool.ntp.org, America/New_York)
  - [ ] MQTT subscribe to all sniperstation/ topics (display all sensor data)
  - [ ] MQTT publish every 60s to `sniperstation/interior/{ROOM_ID}/temperatura|humedad`
- [ ] TimerCam X firmware
  - [ ] Configure RTC wake interval (default: every 4h)
  - [ ] HTTP POST photo to Proxmox LXC endpoint
  - [ ] MQTT publish `sniperstation/camaras/sucufer/captura` after each shot
  - [ ] Deep sleep return after upload (~80µA sleep current)

### Security — Phase 2
> Reference: `docs/security.md` sections 6.6, 10.1, 10.2, 10.4, 10.5, 13.3, 14.4
- [ ] **`secrets.h` must be in `.gitignore` before first firmware commit** — never hardcode WiFi/MQTT credentials in source
  - Create `firmware/station485/secrets.h`, `firmware/cyd_indoor/secrets.h`, `firmware/timercam/secrets.h`
  - Provide `secrets.h.example` with placeholder values for each
- [ ] **Watchdog timer** in all ESP32 firmware (30s) — if loop hangs, device resets instead of leaving pump active
- [ ] **Relay absolute max duration** hardcoded in firmware: force pump OFF after 60s regardless of MQTT commands
- [ ] **Sanitize MQTT pump commands**: accept only `'1'`/`'0'`, length == 1, drop everything else silently
- [ ] **LWT (Last Will and Testament)** configured on all devices: publish `offline` to `sniperstation/sistema/lwt` on unexpected disconnect
- [ ] **Pump state persisted in NVS**: on reboot, if pump was active >2 minutes ago, force relay OFF before connecting to MQTT
- [ ] **OTA with password** configured on all ESP32 — never leave OTA open
- [ ] (Optional) Migrate credentials from `secrets.h` to NVS — allows changing credentials without reflashing

---

## Phase 3 — Software Stack (Proxmox LXC)
**Goal:** Full data pipeline from MQTT to Grafana dashboard + Telegram alerts.

- [ ] Provision LXC container (Debian 12)
- [ ] Install and configure Mosquitto broker
- [ ] Install and configure InfluxDB 2.x
  - [ ] Create org, bucket `sniperstation`, API token
  - [ ] MQTT → InfluxDB bridge (Telegraf or custom Python script)
- [ ] Install and configure Grafana
  - [ ] Connect InfluxDB data source
  - [ ] Build dashboard (7 panels — see README)
  - [ ] Enable mobile-responsive view
- [ ] Telegram Bot
  - [ ] Create bot via BotFather
  - [ ] Implement alert triggers (empty tank, dry soil, high temp, sensor errors)
  - [ ] Implement manual irrigation command via bot
- [ ] Timelapse photo storage service (Proxmox LXC)
  - [ ] HTTP endpoint to receive photos from TimerCam X (Python/Flask or Nginx)
  - [ ] Store photos organized by date: `photos/sucufer/YYYY-MM-DD_HH.jpg`
  - [ ] Grafana panel: display latest photo per plant
  - [ ] Telegram command: `/foto sucufer` → sends latest photo

### Security — Phase 3
> Reference: `docs/security.md` sections 2.1, 3.1–3.3, 4.1–4.4, 5.2–5.3, 6.1–6.5, 7.2–7.3, 9.2, 12.1–12.2, 13.1–13.2, 13.3, 13.5

**Router/Network (before provisioning LXC):**
- [ ] **Disable WPS** on the router — vulnerable to Pixie Dust attack
- [ ] **No port forwarding for Proxmox web UI (port 8006)** to internet — access only from LAN or VPN
- [ ] **Create IoT VLAN** (VLAN 10, 192.168.10.0/24) in pfSense/OPNsense with firewall rules:
  - IoT → LXC: allow ports 1883 (MQTT), 8883 (MQTTS), 443 (HTTPS photos), 123/UDP (NTP)
  - IoT → LAN: **block all**
  - IoT → Internet: allow 443 (OTA updates only)
- [ ] Assign static IPs to all ESP32 via DHCP static mappings (see `docs/security.md` §2.2)
- [ ] Static IP for LXC (192.168.1.50 or equivalent)

**Mosquitto:**
- [ ] **Disable anonymous access**: `allow_anonymous false`
- [ ] Create one MQTT user per device: `station485`, `cyd_master`, `cyd_kids`, `timercam`, `telegraf_bridge`, `telegram_bot`
- [ ] Configure **ACL file** — each device can only publish/subscribe to its own topics (full config in `docs/security.md` §6.2)
- [ ] Enable connection logging to `/var/log/mosquitto/mosquitto.log`

**InfluxDB:**
- [ ] Create **separate tokens with minimal permissions**: write-only for Telegraf, read-only for Grafana
- [ ] Never use the All Access admin token in services

**Grafana:**
- [ ] **Change default admin password** immediately after install (`admin:admin` is the first thing attackers try)
- [ ] Rename admin user, disable sign-up and anonymous access
- [ ] Enable 2FA (TOTP) on admin account
- [ ] Add security monitoring panel: last seen timestamp per device, reconnect counter, pump activation history

**Telegram Bot:**
- [ ] **Restrict bot to authorized `chat_id`** only — reject all other users silently

**HTTP photo endpoint (TimerCam X):**
- [ ] Require **Bearer token authentication** on `/upload` endpoint
- [ ] Configure **nginx rate limiting**: 10 req/min per IP
- [ ] HTTPS for the endpoint (self-signed cert from LXC CA)

**Secrets management:**
- [ ] All secrets in `/etc/sniperstation/secrets.env` — `chmod 600`, loaded via systemd `EnvironmentFile`
- [ ] Correct file permissions on all sensitive files (see `docs/security.md` §9.2)

**Monitoring:**
- [ ] **Fail2ban** for Mosquitto (5 failed auth → 1h ban) and Grafana
- [ ] Telegram alert when any ESP32 publishes `offline` to LWT topic

**MQTTS (after basic stack is working):**
- [ ] Generate self-signed CA + server cert (script in `docs/security.md` §8.2)
- [ ] Configure Mosquitto on port 8883 with TLS 1.2
- [ ] Update all ESP32 firmware with CA cert embedded (`setCACert()`)
- [ ] Switch firewall rule from port 1883 to 8883, remove 1883

---

## Phase 4 — Field Calibration
**Goal:** System tuned to the actual planters and environment.

- [ ] Calibrate Earth Sensors with real planters (dry/moist/wet readings)
- [ ] Calibrate pump flow rate at 12V (measure ml/second with graduated cylinder)
- [ ] Adjust irrigation duration based on measured flow
- [ ] Adjust dry/moist/wet thresholds based on succulent species
- [ ] Stress test: observe full irrigation cycle end-to-end
- [ ] Validate Telegram alerts fire correctly

### Security — Phase 4
- [ ] Verify watchdog fires: simulate a hung loop and confirm the ESP32 resets
- [ ] Verify relay max duration: send MQTT `'1'` and confirm pump stops at 60s regardless
- [ ] Verify LWT: kill WiFi on Station-485 and confirm Telegram alert fires within 30s
- [ ] Verify pump state recovery: cut power mid-pump, confirm relay is OFF after reboot

---

## Phase 5 — Deployment
**Goal:** Permanent outdoor installation.

- [ ] Final enclosure preparation (cable glands, ventilation, mounting)
- [ ] Install Station-485 in outdoor enclosure
- [ ] Route tubing from water reservoir to planters
- [ ] Run 72h unattended monitoring test
- [ ] Document final calibration values in firmware config

### Security — Phase 5
> Reference: `docs/security.md` sections 1.1–1.3, 14.1–14.2
- [ ] Confirm **Torx security screws** installed on outdoor enclosure
- [ ] Confirm **all cable glands sealed** with silicone — no open holes
- [ ] Confirm enclosure is in **permanent shade** — Orlando sun can exceed 60°C inside a closed box
- [ ] Passive ventilation: 10mm holes with mesh at bottom (inlet) and top (outlet) with rain covers
- [ ] Final security audit: verify VLAN rules, MQTTS active, all default passwords changed, `secrets.h` not in git history

---

## Future Ideas

| Feature | Components Needed |
|---|---|
| Generate timelapse GIF/video from stored photos | ffmpeg on Proxmox LXC |
| Second TimerCam X (one per planter) | M5Stack TimerCam X |
| Local audio alert on empty tank | Active Buzzer + Station-485 |
| IR remote irrigation trigger | IR Receiver 38kHz + ESP8266 |
| Auto ventilation fan for enclosure | Fan 5V + Relay + Thermistor |
| Reversible pump (drain tubing) | L293D H-Bridge |
| Expand to more planters | MCP3008 ADC + extra relays |
| Visual water level display | LED Bar Graph (10 segment) |
| Manual control encoder | Rotary Encoder + Station-485 |
| ESP32 flash encryption (AES-256) | — firmware change required |
| LUKS volume encryption for InfluxDB | — Proxmox storage change |
| MQTT topic anomaly monitoring | Custom broker plugin or bridge |

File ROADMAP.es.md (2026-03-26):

# SniperStation — Roadmap

## Fase 1 — Ensamblaje de Hardware
**Objetivo:** Todos los componentes físicos conectados, alimentados y verificados de forma independiente antes de cualquier firmware.

- [ ] Comprar componentes faltantes: adaptador 12V, caja outdoor IP65
- [ ] Rediseñar carcasa 3D para el CYD (marco de pared simple) cuando lleguen los boards
- [ ] Enviar carcasa a imprimir x2 (master bedroom + kids bedroom)
- [ ] Conectar Station-485 con todos los sensores Grove (BH1750, SHT30, Earth Sensors x2)
- [ ] Conectar módulos relay y bombas peristálticas
- [ ] Conectar sensor nivel XKC-Y25 (confirmar asignación de GPIO)
- [ ] Conectar CYD (master): SHT30 en conector CN1 (GPIO21/22), pull-ups 10KΩ
- [ ] Conectar CYD (kids): igual que master
- [ ] Prueba de encendido: verificar 12V → Station-485 + bombas
- [ ] Bench test de cada sensor individualmente (I2C scanner, lecturas analógicas)
- [ ] Bench test pantalla CYD con TFT_eSPI (hello world + calibración de touch)
- [ ] Configuración hardware TimerCam X
  - [ ] Probar WiFi y captura de foto de la TimerCam X
  - [ ] Montar en caja outdoor con ventana de acrílico apuntando a los materos
  - [ ] Confirmar alimentación 5V USB-C (buck converter LM2596 desde rail 12V)
  - [ ] Ajustar buck converter a 5V usando el display voltímetro integrado

---

## Fase 2 — Desarrollo de Firmware
**Objetivo:** Todos los microcontroladores leyendo sensores y publicando a MQTT.

- [ ] Firmware Station-485 (Arduino IDE)
  - [ ] Lectura I2C: BH1750 + SHT30
  - [ ] Lectura analógica humedad suelo (B1=SucuFer, B2=SucuRod)
  - [ ] Lectura digital nivel agua (XKC-Y25)
  - [ ] Control relay para bombas (C1=SucuFer, C2=SucuRod)
  - [ ] WiFi + publicación MQTT
  - [ ] Lógica de riego (ciclo 6h, RTC BM8563)
  - [ ] MQTT subscribe para comandos manuales de riego
  - [ ] Estado en pantalla 1.14" integrada
  - [ ] Soporte bilingüe EN/ES (selección por menú, guardado en NVS)
- [ ] Firmware CYD ESP32-2432S028 — idéntico para ambas unidades, `ROOM_ID` configurable (Arduino IDE)
  - [ ] Lectura SHT30 I2C via CN1 (GPIO21 SDA, GPIO22 SCL)
  - [ ] Init pantalla TFT via librería TFT_eSPI
  - [ ] Screensaver: cactus animado + resumen compacto de temperaturas (timeout 30s)
  - [ ] Vista principal: todos los cuartos + exterior + humedad suelo
  - [ ] Vista detalle: toca una planta → foto de fondo + datos + edad de planta
  - [ ] Manejo touch resistivo (XPT2046) → navegación entre vistas
  - [ ] Selección de idioma EN/ES — por dispositivo, guardado en NVS flash
  - [ ] Strings bilingüe en `strings.h` — `STR_xxx[2]` con índice `lang` (0=EN, 1=ES)
  - [ ] Brillo adaptivo: activo 255, screensaver 30, modo nocturno 00–06h apagado
  - [ ] WiFi + sincronización NTP (pool.ntp.org, America/New_York)
  - [ ] MQTT subscribe a todos los topics de sniperstation/ (muestra todos los datos)
  - [ ] MQTT publish cada 60s a `sniperstation/interior/{ROOM_ID}/temperatura|humedad`

---

## Fase 3 — Stack de Software (Proxmox LXC)
**Objetivo:** Pipeline completo de datos MQTT → dashboard Grafana + alertas Telegram.

- [ ] Provisionar contenedor LXC (Debian 12)
- [ ] Instalar y configurar broker Mosquitto
- [ ] Instalar y configurar InfluxDB 2.x
  - [ ] Crear org, bucket `sniperstation`, API token
  - [ ] Bridge MQTT → InfluxDB (Telegraf o script Python personalizado)
- [ ] Instalar y configurar Grafana
  - [ ] Conectar fuente de datos InfluxDB
  - [ ] Construir dashboard (paneles: exterior, master, kids, SucuFer, SucuRod, nivel agua)
  - [ ] Habilitar vista responsive para celular
- [ ] Bot Telegram
  - [ ] Crear bot via BotFather
  - [ ] Implementar triggers de alerta (recipiente vacío, suelo seco, temp alta, errores)
  - [ ] Implementar comando manual de riego via bot
  - [ ] Soporte bilingüe EN/ES en mensajes del bot
- [ ] Firmware TimerCam X
  - [ ] Configurar intervalo de despertar RTC (por defecto: cada 4h)
  - [ ] HTTP POST de foto al endpoint en Proxmox LXC
  - [ ] Publicar MQTT `sniperstation/camaras/sucufer/captura` después de cada toma
  - [ ] Retornar a deep sleep tras la subida (~2µA sleep)
- [ ] Servicio de almacenamiento de fotos timelapse (Proxmox LXC)
  - [ ] Endpoint HTTP para recibir fotos desde TimerCam X (Python/Flask o Nginx)
  - [ ] Guardar fotos organizadas por fecha: `photos/sucufer/YYYY-MM-DD_HH.jpg`
  - [ ] Panel Grafana: mostrar última foto por planta
  - [ ] Comando Telegram: `/foto sucufer` envía la última foto

---

## Fase 4 — Calibración en Campo
**Objetivo:** Sistema ajustado a los materos reales y el ambiente.

- [ ] Calibrar Earth Sensors con los materos reales (lecturas seco/húmedo/mojado)
- [ ] Calibrar caudal de bombas a 12V (medir ml/segundo con probeta graduada)
- [ ] Ajustar duración de riego según caudal medido
- [ ] Ajustar umbrales de seco/húmedo/mojado para la especie de suculenta
- [ ] Stress test: observar ciclo completo de riego de principio a fin
- [ ] Validar que las alertas Telegram se disparan correctamente

---

## Fase 5 — Instalación Definitiva
**Objetivo:** Instalación outdoor permanente.

- [ ] Preparación final de caja exterior (prensaestopas, ventilación, montaje)
- [ ] Instalar Station-485 en caja weatherproof outdoor
- [ ] Tender tuberías desde el recipiente de agua hasta los materos
- [ ] Ejecutar prueba de monitoreo de 72h sin supervisión
- [ ] Documentar valores finales de calibración en la config del firmware

---

## Ideas Futuras

| Feature | Componentes Necesarios |
|---|---|
| Generar GIF/video timelapse desde fotos almacenadas | ffmpeg en Proxmox LXC |
| Segunda TimerCam X (una por matero) | M5Stack TimerCam X |
| Alerta sonora local cuando recipiente vacío | Active Buzzer + Station-485 |
| Control remoto IR del riego | IR Receiver 38kHz + ESP8266 |
| Ventilador automático para la caja | Fan 5V + Relay + Termistor |
| Bomba reversible (drenar mangueras) | L293D H-Bridge |
| Expandir a más materos | MCP3008 ADC + relays adicionales |
| Display visual nivel de agua | LED Bar Graph (10 segmentos) |
| Control manual con encoder rotativo | Rotary Encoder + Station-485 |

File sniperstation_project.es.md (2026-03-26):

# SniperStation — Proyecto Completo
> Documento de contexto para Claude Code  
> Generado desde sesión de planificación en Claude.ai

---

## 📋 Descripción del Proyecto

Sistema automático de riego + estación meteorológica para dos materos de suculentas ubicados **afuera** de una casa en **Orlando, Florida**. El sistema monitorea condiciones ambientales (temperatura, humedad, luz solar, humedad del suelo) y riega automáticamente en base a sensores, con dashboard web, alertas por Telegram e historial de datos.

---

## 🏗️ Arquitectura del Sistema

```
[AFUERA]                                    [ADENTRO]
Station-485 (cerebro principal)             ESP8266 NodeMCU
├── DLight BH1750    → Puerto A1            └── SHT30 interior (temp/hum AC)
├── SHT30 exterior   → Puerto A2                │
├── Earth Sensor 1   → Puerto B1                │
├── Earth Sensor 2   → Puerto B2                │
├── Relay Bomba 1    → Puerto C1                │
├── Relay Bomba 2    → Puerto C2                │
└── Sensor nivel H2O → Puerto B o C             │
     (XKC-Y25)                                  │
          │                                     │
          └──────── WiFi → MQTT ────────────────┘
                         │
                  [Proxmox LXC]
                  ├── Mosquitto (MQTT broker)
                  ├── InfluxDB (base de datos series de tiempo)
                  ├── Grafana (dashboard web / celular)
                  └── Bot Telegram (alertas)
```

---

## 📦 Lista Completa de Hardware
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

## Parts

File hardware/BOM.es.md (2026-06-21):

# Lista de Materiales — SniperStation

**Última actualización:** 2026-06-21
**Proyecto:** SniperStation — Riego automático de suculentas + estación meteorológica
**Ubicación:** Orlando, Florida (exterior, expuesto al sol y lluvia)

## Leyenda de Estado

| Estado | Significado |
|---|---|
| ✅ En mano | Físicamente disponible |
| 🚚 En tránsito | Comprado, en tránsito |
| 🛒 Por comprar | Aún no comprado |

---

## Componentes Principales

| # | Componente | Modelo / Parte | Cant | Voltaje | Notas | Proveedor | Estado |
|---|---|---|---|---|---|---|---|
| 1 | Controlador principal | M5Stack Station-485 | 1 | 9–24V entrada | ESP32, WiFi, pantalla 1.14", 6x Grove HY2.0, RS485, RTC BM8563 | M5Stack | ✅ En mano |
| 2 | Sensor de luz | DLight BH1750 | 1 | 3.3–5V | Dirección I2C 0x23, rango 1–65535 lx, Grove HY2.0 | M5Stack | ✅ En mano |
| 3 | Sensor temp/humedad (exterior) | SHT30 IOT-TH02 | 1 | 2.15–5.5V | Dirección I2C 0x44, cables sueltos codificados por color | Amazon | ✅ En mano |
| 4 | Sensor temp/humedad (interior) | SHT30 IOT-TH02 | 1 | 2.15–5.5V | Dirección I2C 0x44, cables sueltos codificados por color | Amazon | ✅ En mano |
| 5 | Sensor humedad de suelo | M5Stack Earth Sensor | 2 | 3.3–5V | Salida analógica + digital, Grove HY2.0 | M5Stack | ✅ En mano |
| 6 | Módulo relay | M5Stack Mini Relay 3A | 2 | 5V control | 3A/30VDC, Grove HY2.0, NO/NC/COM | M5Stack | ✅ En mano |
| 7 | Bomba peristáltica | Bomba DC 12–24V | 2 | 12V | ~100 ml/min, 80mA, reversible, tuberías incluidas | Amazon | ✅ En mano |
| 8 | Sensor nivel agua | XKC-Y25-V + driver DFRobot | 1 | 5–24V | Sin contacto capacitivo, salida digital, 4 niveles de sensibilidad | Amazon | ✅ En mano |
| 9 | Unidad interior (todo en uno) | ESP32-2432S028 CYD | 2 | 5V USB | ESP32 dual-core + TFT 2.8" 240x320 color + táctil resistivo. Una por habitación (principal + niños). I2C SHT30 en CN1 (GPIO21/22) | Amazon | ✅ En mano |
| 10 | Cable Grove↔Dupont | HY2.0-4P a 2.54mm hembra 20cm | 2 | — | Conecta SHT30 a puertos Grove Station-485. WatangTech en Amazon | Amazon | ✅ En mano |
| 11 | Cámara timelapse | M5Stack ESP32 PSRAM Timer Camera X (OV3660) | 1 | 5V USB | 3MP 2048x1536, FOV 66.5°, WiFi, RTC BM8563, batería 140mAh, sleep 2µA. Una unidad cubre ambos materos. 48x24x15mm | M5Stack | ✅ En mano |

---

## Componentes de Alimentación y Enclosure

| # | Componente | Especificación | Cant | Notas | Proveedor | Costo Estimado |
|---|---|---|---|---|---|---|
| 13 | Adaptador DC | 12V 2A, conector barrel 5.5x2.1mm | 1 | Alimenta Station-485 + ambas bombas desde una sola fuente | Amazon | ✅ En mano |
| 16 | Convertidor buck DC-DC | LM2596 ajustable, 4–40V entrada, 1.25–37V salida, 2A | 2 | Fijar salida en 5V (voltímetro incorporado). Alimenta TimerCam X desde riel 12V. 1 unidad + 1 repuesto | Amazon | ✅ En mano |
| 17 | Conectores de distribución | Wago 221-415 (5 puertos) | 2 | Uno para riel +12V, uno para riel GND. Sin soldadura. 1 entrada → 4 salidas cada uno | Amazon | ✅ En mano |
| 14 | Enclosure exterior resistente | IP65 mín, 150x120x80mm mín, ranuras de ventilación o montaje para ventilador | 1 | Debe soportar el calor del verano de Orlando — instalación en sombra obligatoria | Amazon | ✅ En mano |
| 15 | Enclosure unidad interior x2 | Impresión 3D personalizada | 2 | Contiene CYD ESP32-2432S028 + SHT30 (marco de pared). Mismo diseño impreso dos veces | Servicio 3D | ✅ En mano |

---

## Componentes de Soporte (del Kit SunFounder / Inventario)

Usados durante el prototipado y ensamblaje. Marcados con uso previsto.

| Componente | Cant | Valor | Uso en SniperStation |
|---|---|---|---|
| Resistor | 2 | 10KΩ | Pull-ups I2C en CN1 SDA/SCL del CYD para SHT30 (1 por unidad x 2 unidades) |
| Diodo 1N4007 | 2 | — | Protección flyback en salidas de relay de bombas |
| Capacitor electrolítico | 2 | 10µF | Filtro de ruido de alimentación cerca de relays de bombas |
| Cable jumper H/H | 4 | 20cm | Conexiones CYD CN1 ↔ SHT30 interior |
| Cable jumper M/M | 6 | 20cm | Prototipado en breadboard |
| Ventilador (5V DC) | 1 (opcional) | — | Ventilación del enclosure si la ventilación pasiva es insuficiente |

---

## No Usados en SniperStation (reservados para proyectos futuros)

| Componente | Cant | Uso Potencial |
|---|---|---|
| ESP8266 NodeMCU CP2102 | 2 | Liberados — proyectos futuros |
| Sensor táctil TTP223 | 2 | Liberados — proyectos futuros |
| HC-SR04 ultrasónico | 1 | Sensor alternativo de nivel de agua |
| L293D H-Bridge | 1 | Control reversible de bomba (drenar tuberías después del riego) |
| MCP3008 ADC | 1 | Expansión a más materos (más entradas analógicas) |
| Módulo de cámara (genérico) | 1 | Reemplazado por M5Stack TimerCam X (ordenado) |
| Sensor PIR de movimiento | 1 | Detección de presencia en el jardín |

---

## Presupuesto de Potencia

| Componente | Voltaje | Corriente (típica) | Corriente (pico) |
|---|---|---|---|
| Station-485 (reposo) | 12V | 120mA | — |
| Station-485 (WiFi activo) | 12V | 161mA | 200mA |
| Bomba 1 (activa) | 12V | 80mA | 100mA |
| Bomba 2 (activa) | 12V | 80mA | 100mA |
| Sensores Grove total | 5V (interno) | ~20mA | — |
| **Total (ambas bombas + WiFi)** | **12V** | **~341mA** | **~400mA** |

**Adaptador:** 12V 2A → capacidad 2000mA vs 400mA consumo pico. Margen de seguridad: **5x**. ✅

> Nota: Ambas bombas no se activarán simultáneamente por diseño (un matero a la vez).
> Peor caso real: 161mA (controlador) + 80mA (una bomba) = 241mA.

---

## Referencias de Datasheets

Ver [datasheets/SOURCES.md](datasheets/SOURCES.md) para los enlaces a todos los datasheets de componentes.

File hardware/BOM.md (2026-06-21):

# Bill of Materials — SniperStation

**Last updated:** 2026-06-21
**Project:** SniperStation — Automatic succulent irrigation + weather station
**Location:** Orlando, Florida (outdoor, exposed to sun and rain)

## Status Legend

| Status | Meaning |
|---|---|
| ✅ In hand | Physically on hand |
| 🚚 In transit | Purchased, in transit |
| 🛒 To buy | Not yet purchased |

---

## Primary Components

| # | Component | Model / Part | Qty | Voltage | Notes | Supplier | Status |
|---|---|---|---|---|---|---|---|
| 1 | Main controller | M5Stack Station-485 | 1 | 9–24V input | ESP32, WiFi, 1.14" display, 6x Grove HY2.0, RS485, RTC BM8563 | M5Stack | ✅ In hand |
| 2 | Light sensor | DLight BH1750 | 1 | 3.3–5V | I2C address 0x23, range 1–65535 lx, Grove HY2.0 | M5Stack | ✅ In hand |
| 3 | Temp/humidity sensor (outdoor) | SHT30 IOT-TH02 | 1 | 2.15–5.5V | I2C address 0x44, loose color-coded wires | Amazon | ✅ In hand |
| 4 | Temp/humidity sensor (indoor) | SHT30 IOT-TH02 | 1 | 2.15–5.5V | I2C address 0x44, loose color-coded wires | Amazon | ✅ In hand |
| 5 | Soil moisture sensor | M5Stack Earth Sensor | 2 | 3.3–5V | Analog + digital output, Grove HY2.0 | M5Stack | ✅ In hand |
| 6 | Relay module | M5Stack Mini 3A Relay | 2 | 5V control | 3A/30VDC, Grove HY2.0, NO/NC/COM | M5Stack | ✅ In hand |
| 7 | Peristaltic pump | DC 12–24V pump | 2 | 12V | ~100 ml/min, 80mA, reversible, tubing included | Amazon | ✅ In hand |
| 8 | Water level sensor | XKC-Y25-V + DFRobot driver | 1 | 5–24V | Non-contact capacitive, digital output, 4 sensitivity levels | Amazon | ✅ In hand |
| 9 | Indoor unit (all-in-one) | ESP32-2432S028 CYD | 2 | 5V USB | ESP32 dual-core + 2.8" TFT 240x320 color + resistive touch. One per room (master + kids). I2C SHT30 on CN1 (GPIO21/22) | Amazon | ✅ In hand |
| 10 | Grove↔Dupont cable | HY2.0-4P to 2.54mm female 20cm | 2 | — | Connects SHT30 to Station-485 Grove ports. WatangTech on Amazon | Amazon | ✅ In hand |
| 11 | Timelapse camera | M5Stack ESP32 PSRAM Timer Camera X (OV3660) | 1 | 5V USB | 3MP 2048x1536, FOV 66.5°, WiFi, RTC BM8563, battery 140mAh, sleep 2µA. One unit covers both planters. 48x24x15mm | M5Stack | ✅ In hand |

---

## Power & Enclosure Components

| # | Component | Specification | Qty | Notes | Supplier | Estimated Cost |
|---|---|---|---|---|---|---|
| 13 | DC power adapter | 12V 2A, 5.5x2.1mm barrel jack | 1 | Powers Station-485 + both pumps from single source | Amazon | ✅ In hand |
| 16 | DC-DC buck converter | LM2596 adjustable, 4–40V in, 1.25–37V out, 2A | 2 | Set to 5V output (built-in voltmeter display). Powers TimerCam X from 12V rail. 1 unit + 1 spare | Amazon | ✅ In hand |
| 17 | Power distribution connectors | Wago 221-415 lever nuts (5-port) | 2 | One for +12V rail, one for GND rail. No soldering required. 1 input → 4 outputs each | Amazon | ✅ In hand |
| 14 | Outdoor weatherproof enclosure | IP65 min, 150x120x80mm min, ventilation slots or fan mount | 1 | Must handle Orlando summer heat — shade installation mandatory | Amazon | ✅ In hand |
| 15 | Indoor unit enclosure x2 | Custom 3D printed | 2 | Contains CYD ESP32-2432S028 + SHT30 (wall frame). Same design printed twice | 3D Print Service | ✅ In hand |

---

## Supporting Components (from SunFounder Kit / Inventory)

Used during prototyping and assembly. Marked with intended use.

| Component | Qty | Value | Use in SniperStation |
|---|---|---|---|
| Resistor | 2 | 10KΩ | I2C pull-ups on CYD CN1 SDA/SCL for SHT30 (1 per unit x 2 units) |
| Diode 1N4007 | 2 | — | Flyback protection on pump relay outputs |
| Capacitor electrolytic | 2 | 10µF | Power supply noise filter near pump relays |
| Jump wire F/F | 4 | 20cm | CYD CN1 ↔ SHT30 indoor connections |
| Jump wire M/M | 6 | 20cm | Breadboard prototyping |
| Fan (5V DC) | 1 (optional) | — | Enclosure ventilation if passive ventilation is insufficient |

---

## Not Used in SniperStation (reserved for future projects)

| Component | Qty | Potential Use |
|---|---|---|
| ESP8266 NodeMCU CP2102 | 2 | Freed up — future projects |
| TTP223 touch sensor | 2 | Freed up — future projects |
| HC-SR04 ultrasonic | 1 | Alternative water level sensor |
| L293D H-Bridge | 1 | Reversible pump control (drain tubing after irrigation) |
| MCP3008 ADC | 1 | Expansion to more planters (more analog inputs) |
| Camera Module (generic) | 1 | Superseded by M5Stack TimerCam X (ordered) |
| PIR Motion Sensor | 1 | Presence detection in garden |

---

## Power Budget

| Component | Voltage | Current (typical) | Current (peak) |
|---|---|---|---|
| Station-485 (idle) | 12V | 120mA | — |
| Station-485 (WiFi active) | 12V | 161mA | 200mA |
| Pump 1 (active) | 12V | 80mA | 100mA |
| Pump 2 (active) | 12V | 80mA | 100mA |
| Grove sensors total | 5V (internal) | ~20mA | — |
| **Total (both pumps + WiFi)** | **12V** | **~341mA** | **~400mA** |

**Adapter:** 12V 2A → 2000mA capacity vs 400mA peak draw. Safety margin: **5x**. ✅

> Note: Both pumps will not activate simultaneously by design (one planter at a time).
> Real worst case: 161mA (controller) + 80mA (one pump) = 241mA.

---

## Datasheet References

See [datasheets/SOURCES.md](datasheets/SOURCES.md) for links to all component datasheets.

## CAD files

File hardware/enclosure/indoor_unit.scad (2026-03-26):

// ============================================================
// SniperStation — Indoor Unit Enclosure v1.1
// ============================================================
// Contents:   ESP8266 NodeMCU CP2102 + SSH1106 OLED 1.3"
//             TTP223 touch sensor + SHT30 cased sensor (top)
// Mount:      Wall via keyhole slots on back plate
// USB exit:   Bottom face
//
// HOW TO PRINT:
//   Set PART = "shell"      → export shell STL
//   Set PART = "back_plate" → export back plate STL
//   Set PART = "all"        → preview both side by side
//
// PRINT ORIENTATION:
//   Shell:      front face DOWN on print bed (rotate -90° in slicer on X axis)
//   Back plate: flat face DOWN, no rotation needed
//
// License: CERN OHL v2 Permissive
// ============================================================
//
// Coordinate system (before slicer rotation):
//   x = width    (0 = left,   ext_w = right)
//   y = depth    (0 = front,  ext_d = back)
//   z = height   (0 = bottom, ext_h = top)
//
// ⚠️  Measurements to verify before first print:
//   - SHT30 casing actual dimensions (measured: ~35 x 20 x 12mm) — UPDATE when received
//   - NodeMCU PCB actual dimensions  (nominal:  49 x 26mm)
//   - OLED PCB actual dimensions     (nominal:  38.5 x 23mm)
//   - TTP223 PCB measured: 22.2 x 22.2mm (7/8" x 7/8") ✅
// ============================================================

/* [Part selector] */
PART = "all";    // "all" | "shell" | "back_plate"

/* [Shell — outer dimensions] */
wall  = 2.0;    // wall thickness (mm)
ext_w = 70.0;   // external width
ext_h = 90.0;   // external height (excl. SHT30 protrusion above top)
ext_d = 36.0;   // external depth (front face to back opening)

/* [OLED SSH1106 1.3"] */
// Visible window (show display glass area through front face)
oled_win_w       = 31.0;    // window width
oled_win_h       = 23.0;    // window height
oled_top_margin  = 14.0;    // distance from box top to top edge of window
// PCB dimensions (38.5 x 23mm + tolerance)
oled_pcb_w       = 39.5;    // PCB width  + 1mm tolerance
oled_pcb_h       = 24.0;    // PCB height + 1mm tolerance
// Retention frame depth (from inner face of front wall into interior)
oled_frame_d     =  6.0;

/* [TTP223 Touch Sensor] */
// No hole — capacitive sensing works through 2mm PLA
// Concentric rings engraved on front face indicate touch zone
touch_cz         = 22.0;    // touch area center height from box bottom
touch_ring_max_r =  9.0;    // outermost engraved ring radius
touch_ring_count =  4;      // number of concentric rings
touch_ring_depth =  0.5;    // engraving depth (mm)
touch_ring_w     =  0.8;    // ring line width (mm)
// TTP223 PCB measured: 22.2 x 22.2mm (7/8" x 7/8")
// Right-angle header — pins exit upward into interior (no interference)
ttp_pcb_w        = 23.0;    // 22.2mm + 0.8mm tolerance
ttp_pcb_h        = 23.0;    // 22.2mm + 0.8mm tolerance
ttp_shelf_depth  =  4.0;    // shelf depth from inner front wall

/* [USB slot — bottom face] */
usb_w = 12.0;   // slot width  (micro-USB plug + cable clearance)
usb_h =  9.0;   // slot height

/* [SHT30 cased sensor — top face] */
// ⚠️  Measure your actual SHT30 casing before printing
sht30_casing_w = 36.0;   // casing width  (measured)
sht30_casing_d = 21.0;   // casing depth  (measured)
sht30_lip      =  1.0;   // retaining lip on each side

/* [NodeMCU CP2102] */
// ⚠️  Verify your actual board — some versions differ
mcu_len        = 49.0;   // PCB length (long axis, vertical in enclosure)
mcu_wid        = 26.0;   // PCB width  (short axis, front-to-back)
mcu_ledge_h    =  3.0;   // standoff height (clears USB connector below)
mcu_ledge_w    =  5.0;   // ledge width (support surface)

/* [Back plate attachment] */
boss_od        =  7.0;   // boss outer diameter
boss_id        =  2.3;   // M2 pilot hole diameter
boss_depth     =  8.0;   // pilot hole depth (from back end)

/* [Keyhole slots — wall mounting] */
kh_big_d       =  5.8;   // large circle diameter (M3 screw head clears)
kh_sml_d       =  3.4;   // small circle diameter (M3 shaft, holds)
kh_slot_len    =  8.0;   // slot length (slide distance)
kh_spacing     = 50.0;   // horizontal center-to-center
kh_cz          = ext_h - 20.0;  // small circle center height from bottom

// ── Derived values ───────────────────────────────────────────

int_w = ext_w - 2 * wall;
int_h = ext_h - 2 * wall;

// OLED window center
oled_cx = ext_w / 2;
oled_cz = ext_h - oled_top_margin - oled_win_h / 2;

// Touch hole center
touch_cx = ext_w / 2;

// SHT30 slot outer opening
sht30_slot_w = sht30_casing_w + 2 * sht30_lip;
sht30_slot_d = sht30_casing_d + 2 * sht30_lip;

// Boss corner positions [x, z] — inside enclosure, near back corners
boss_pos = [
    [  9.0,   9.0 ],   // bottom-left
    [ 61.0,   9.0 ],   // bottom-right
    [  9.0,  81.0 ],   // top-left
    [ 61.0,  81.0 ],   // top-right
];

// ── Module: main shell ───────────────────────────────────────

module shell() {
    difference() {
        // Outer solid block
        cube([ext_w, ext_d, ext_h]);

        // Hollow interior — open at back (y = ext_d)
        translate([wall, wall, wall])
            cube([int_w, ext_d + 1, int_h]);

        // OLED window — front face (y = 0)
        translate([oled_cx - oled_win_w/2, -0.1, oled_cz - oled_win_h/2])
            cube([oled_win_w, wall + 0.2, oled_win_h]);

        // Touch zone — concentric rings engraved on front face (no hole)
        // Capacitive field penetrates 2mm PLA without issue
        for (i = [0 : touch_ring_count - 1]) {
            r = touch_ring_max_r - i * (touch_ring_max_r / touch_ring_count);
            translate([touch_cx, -0.1, touch_cz])
                rotate([-90, 0, 0])
                difference() {
                    cylinder(r=r,               h=touch_ring_depth + 0.1, $fn=64);
                    cylinder(r=r - touch_ring_w, h=touch_ring_depth + 0.2, $fn=64);
                }
        }

        // USB slot — bottom face (y from wall to ext_d-wall, centered in x)
        translate([(ext_w - usb_w) / 2, wall, -0.1])
            cube([usb_w, ext_d - 2 * wall, usb_h + 0.1]);

        // SHT30 slot — top face (centered, with retaining lip)
        translate([
            (ext_w - sht30_casing_w) / 2,
            (ext_d - sht30_casing_d) / 2,
            ext_h - wall - 0.1
        ])
            cube([sht30_casing_w, sht30_casing_d, wall + 0.2]);
    }
}

// ── Module: OLED retention frame ────────────────────────────
// Creates a U-channel inside the front wall to guide and hold the OLED PCB.
// OLED PCB slides in from the open back and rests against the front wall.
// PCB width (39.5mm) > window width (31mm) → PCB cannot fall through.

module oled_frame() {
    frame_t = 1.5;   // frame rail thickness

    pcb_x1 = oled_cx - oled_pcb_w / 2;
    pcb_x2 = oled_cx + oled_pcb_w / 2;
    pcb_z1 = oled_cz - oled_pcb_h / 2;
    pcb_z2 = oled_cz + oled_pcb_h / 2;

    // Bottom shelf — PCB rests on this
    translate([pcb_x1 - frame_t, wall, pcb_z1 - frame_t])
        cube([oled_pcb_w + 2 * frame_t, oled_frame_d, frame_t]);

    // Left rail
    translate([pcb_x1 - frame_t, wall, pcb_z1 - frame_t])
        cube([frame_t, oled_frame_d, oled_pcb_h + 2 * frame_t]);

    // Right rail
    translate([pcb_x2, wall, pcb_z1 - frame_t])
        cube([frame_t, oled_frame_d, oled_pcb_h + 2 * frame_t]);

    // Top lip — prevents PCB from tilting out at top
    translate([pcb_x1 - frame_t, wall, pcb_z2])
        cube([oled_pcb_w + 2 * frame_t, frame_t, frame_t]);
}

// ── Module: TTP223 mount shelf ───────────────────────────────
// Square pocket behind the touch zone on the front face.
// TTP223 PCB (22.2 x 22.2mm) slides in and sits flush against front wall.
// Touch pad faces forward (toward engraved rings on front face).
// Right-angle header pins exit upward into the open interior — no interference.

module touch_shelf() {
    translate([touch_cx - ttp_pcb_w / 2, wall, touch_cz - ttp_pcb_h / 2])
        difference() {
            // Shelf frame (outer)
            cube([ttp_pcb_w, ttp_shelf_depth, ttp_pcb_h]);
            // PCB pocket (inner — PCB slides in from open back)
            translate([0.5, 0, 0.5])
                cube([ttp_pcb_w - 1, ttp_shelf_depth + 0.1, ttp_pcb_h - 1]);
        }
}

// ── Module: back plate screw bosses ─────────────────────────
// Hollow bosses in the four interior corners.
// M2 screws go through back plate into these bosses to close the enclosure.

module bosses() {
    boss_h = ext_d - 2 * wall;   // boss from inner front wall to back opening

    for (p = boss_pos) {
        translate([p[0] - boss_od/2, wall, p[1] - boss_od/2])
            difference() {
                cube([boss_od, boss_h, boss_od]);
                // Pilot hole from back end
                translate([boss_od/2, boss_h - boss_depth, boss_od/2])
                    cylinder(d=boss_id, h=boss_depth + 0.1, $fn=16);
            }
    }
}
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

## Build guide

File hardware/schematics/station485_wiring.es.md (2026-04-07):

# Diagrama de Conexiones — Station-485

**Controlador:** M5Stack Station-485 (ESP32-D0WDQ6)
**Voltaje de entrada:** 9–24V DC via conector barrel PWR485
**Puertos Grove:** HY2.0-4P 4 pines (Orden de pines: GND, VCC, GPIO_B, GPIO_A)

---

## Asignación de Puertos Grove

```
Station-485
┌────────────────────────────────────────────────────────┐
│                                                        │
│  ┌──────┐                                              │
│  │ A1   │ GND │ 5V │ G33(SCL) │ G32(SDA) ──► BH1750  │
│  ├──────┤                                              │
│  │ A2   │ GND │ 5V │ G33(SCL) │ G32(SDA) ──► SHT30   │
│  │      │     │    │  (bus I2C compartido A1+A2)       │
│  ├──────┤                                              │
│  │ B1   │ GND │ 5V │ G35      │ G25      ──► Tierra S1│
│  ├──────┤                                              │
│  │ B2   │ GND │ 5V │ G36(IN)  │ G26      ──► Tierra S2│
│  │      │     │    │  ⚠️ G36 solo entrada              │
│  ├──────┤                                              │
│  │ C1   │ GND │ 5V │ G17      │ G14      ──► Relay 1  │
│  ├──────┤                                              │
│  │ C2   │ GND │ 5V │ G19      │ G17      ──► Relay 2  │
│  └──────┘                                              │
│                                                        │
│  Salida USB-A 5V ──────────────────────► XKC-Y25 VCC  │
│  GPIO (TBD) ───────────────────────────► XKC-Y25 OUT  │
│                                                        │
│  PWR485 ──────────────────────────────► Entrada 12V 2A │
└────────────────────────────────────────────────────────┘
```

> **⚠️ Asignación GPIO de XKC-Y25 pendiente:** Los puertos B1, B2, C1, C2 están totalmente ocupados.
> Opciones: usar un pin GPIO del header expuesto directamente, o remapear si se libera un puerto Grove.
> **Confirmar antes de escribir el firmware.** Actualizar este archivo con el número GPIO final.

---

## Sensor de Luz BH1750 — Puerto A1

```
Cable Grove (A1)          BH1750
─────────────────────────────────────────
Negro  (GND)    ──────►  GND
Rojo   (VCC 5V) ──────►  VCC
Blanco (SCL)    ──────►  SCL   (G33)
Amarillo (SDA)  ──────►  SDA   (G32)
```

- Dirección I2C: **0x23** (pin ADDR flotante o a GND)
- Rango: 1 – 65,535 lx
- Modos de resolución: 1 lx (alta res), 0.5 lx (alta res 2)

---

## SHT30 Exterior — Puerto A2

```
Cable Grove (A2)          SHT30 IOT-TH02 (cables sueltos)
────────────────────────────────────────────────────────
Negro  (GND)    ──────►  Negro  (GND)
Rojo   (VCC 5V) ──────►  Rojo   (VCC)
Blanco (SCL)    ──────►  Amarillo (SCL)  ⚠️ COLORES CRUZADOS
Amarillo (SDA)  ──────►  Blanco (SDA)   ⚠️ COLORES CRUZADOS
```

- Dirección I2C: **0x44** (por defecto, ADDR no elevado)
- Comparte bus I2C con BH1750 (0x23) — sin conflicto de dirección ✅
- Precisión temperatura: ±0.3°C | Precisión humedad: ±2% RH

---

## Sensor de Tierra SucuFer — Puerto B1

```
Cable Grove (B1)          Sensor Earth M5Stack
─────────────────────────────────────────────────
Negro  (GND)    ──────►  GND
Rojo   (VCC 5V) ──────►  VCC
Blanco (G35)    ──────►  AOUT  (salida analógica)
Amarillo (G25)  ──────►  DOUT  (salida digital de umbral)
```

- Lectura analógica en **G25** (ADC1_CH8)
- Rango analógico: 0–4095 (ADC de 12 bits)
- Se requiere calibración: medir valor crudo en suelo seco y suelo saturado

---

## Sensor de Tierra SucuRod — Puerto B2

```
Cable Grove (B2)          Sensor Earth M5Stack
─────────────────────────────────────────────────
Negro  (GND)    ──────►  GND
Rojo   (VCC 5V) ──────►  VCC
Blanco (G36)    ──────►  AOUT  (analógico — G36 es SOLO ENTRADA) ✅
Amarillo (G26)  ──────►  DOUT  (salida digital de umbral)
```

> **⚠️ G36 es solo entrada en ESP32.** Usar únicamente para leer valores analógicos. Nunca configurar como salida.

---

## Relay SucuFer (→ Bomba SucuFer) — Puerto C1

```
Cable Grove (C1)          M5Stack Mini Relay 1
──────────────────────────────────────────────────
Negro  (GND)    ──────►  GND
Rojo   (VCC 5V) ──────►  VCC
Amarillo (G14)  ──────►  IN   (señal — HIGH = relay ON)

Contactos Relay 1          Bomba 1
──────────────────────────────────────────────────
COM             ──────►  +12V (del adaptador DC)
NO              ──────►  Bomba 1 (cable rojo +)
(GND común compartido con GND de la bomba)
```

---

## Relay SucuRod (→ Bomba SucuRod) — Puerto C2

```
Cable Grove (C2)          M5Stack Mini Relay 2
──────────────────────────────────────────────────
Negro  (GND)    ──────►  GND
Rojo   (VCC 5V) ──────►  VCC
Amarillo (G17)  ──────►  IN   (señal — HIGH = relay ON)

Contactos Relay 2          Bomba 2
──────────────────────────────────────────────────
COM             ──────►  +12V (del adaptador DC)
NO              ──────►  Bomba 2 (cable rojo +)
(GND común compartido con GND de la bomba)
```

---

## Sensor de Nivel de Agua XKC-Y25-V

```
Placa Driver DFRobot       Station-485
──────────────────────────────────────────────────
VCC             ──────►  5V (salida USB-A)
GND             ──────►  GND
OUT             ──────►  GPIO (TBD — confirmar puerto)

Sonda del sensor ──────►  Pegar en el exterior del recipiente de agua (plástico)
```

- Salida: HIGH = agua presente en la posición del sensor, LOW = vacío
- Sensibilidad: ajustable con el botón SET en la placa driver (4 niveles)
- Para recipientes plásticos con pared ≤ 3mm

---

## Distribución de Alimentación

```
Adaptador 12V 2A DC (conector barrel 5.5x2.1mm)
        │
        └──► PWR485 (entrada de alimentación Station-485)
                │
                ├── Regula a 5V para puertos Grove (interno)
                ├── Regula a 3.3V para núcleo ESP32 (interno)
                │
                ├── Relay 1 COM ──► Bomba 1 (+)
                └── Relay 2 COM ──► Bomba 2 (+)

Riel GND (común):
    GND adaptador DC ──► GND Station-485 ──► Bomba 1 (-) ──► Bomba 2 (-)

Recomendado: Diodo flyback 1N4007 en cada bomba (cátodo a +12V, ánodo a GND)
Recomendado: Capacitor electrolítico 10µF en los rieles de alimentación cerca de los relays
```

---

## Resumen Bus I2C (Puertos A1 + A2 — compartidos G32/G33)

| Dispositivo | Dirección | Puerto |
|---|---|---|
| BH1750 | 0x23 | A1 |
| SHT30 exterior | 0x44 | A2 |

Sin conflicto de dirección. Ambos responden en los mismos cables SDA/SCL. ✅

---

## Resumen GPIO

| GPIO | Función | Dirección | Puerto |
|---|---|---|---|
| G32 | I2C SDA | E/S | A1 + A2 |
| G33 | I2C SCL | E/S | A1 + A2 |
| G25 | Sensor tierra SucuFer analógico | ENTRADA | B1 |
| G35 | Sensor tierra SucuFer digital | ENTRADA | B1 |
| G26 | Sensor tierra SucuRod analógico | ENTRADA | B2 |
| G36 | Sensor tierra SucuRod digital (solo entrada) | ENTRADA | B2 |
| G14 | Control Relay 1 | SALIDA | C1 |
| G17 | Control Relay 2 | SALIDA | C2 |
| TBD | Señal XKC-Y25 | ENTRADA | — |

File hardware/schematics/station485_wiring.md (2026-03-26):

# Station-485 Wiring Diagram

**Controller:** M5Stack Station-485 (ESP32-D0WDQ6)
**Input voltage:** 9–24V DC via PWR485 barrel jack
**Grove ports:** HY2.0-4P 4-pin (Pin order: GND, VCC, GPIO_B, GPIO_A)

---

## Grove Port Assignments

```
Station-485
┌────────────────────────────────────────────────────────┐
│                                                        │
│  ┌──────┐                                              │
│  │ A1   │ GND │ 5V │ G33(SCL) │ G32(SDA) ──► BH1750  │
│  ├──────┤                                              │
│  │ A2   │ GND │ 5V │ G33(SCL) │ G32(SDA) ──► SHT30   │
│  │      │     │    │  (shared I2C bus A1+A2)           │
│  ├──────┤                                              │
│  │ B1   │ GND │ 5V │ G35      │ G25      ──► Earth S1 │
│  ├──────┤                                              │
│  │ B2   │ GND │ 5V │ G36(IN)  │ G26      ──► Earth S2 │
│  │      │     │    │  ⚠️ G36 input only               │
│  ├──────┤                                              │
│  │ C1   │ GND │ 5V │ G17      │ G14      ──► Relay 1  │
│  ├──────┤                                              │
│  │ C2   │ GND │ 5V │ G19      │ G17      ──► Relay 2  │
│  └──────┘                                              │
│                                                        │
│  USB-A 5V output ──────────────────────► XKC-Y25 VCC  │
│  GPIO (TBD) ───────────────────────────► XKC-Y25 OUT  │
│                                                        │
│  PWR485 ──────────────────────────────► 12V 2A input  │
└────────────────────────────────────────────────────────┘
```

> **⚠️ XKC-Y25 GPIO assignment pending:** Ports B1, B2, C1, C2 are fully used.
> Options: use an exposed GPIO header pin directly, or remap if a Grove port is freed.
> **Confirm before writing firmware.** Update this file with final GPIO number.

---

## BH1750 Light Sensor — Port A1

```
Grove Cable (A1)          BH1750
─────────────────────────────────────────
Black  (GND)    ──────►  GND
Red    (VCC 5V) ──────►  VCC
White  (SCL)    ──────►  SCL   (G33)
Yellow (SDA)    ──────►  SDA   (G32)
```

- I2C address: **0x23** (ADDR pin floating or tied to GND)
- Range: 1 – 65,535 lx
- Resolution modes: 1 lx (high res), 0.5 lx (high res 2)

---

## SHT30 Outdoor — Port A2

```
Grove Cable (A2)          SHT30 IOT-TH02 (loose wires)
────────────────────────────────────────────────────────
Black  (GND)    ──────►  Black  (GND)
Red    (VCC 5V) ──────►  Red    (VCC)
White  (SCL)    ──────►  Yellow (SCL)  ⚠️ COLORS CROSSED
Yellow (SDA)    ──────►  White  (SDA)  ⚠️ COLORS CROSSED
```

- I2C address: **0x44** (default, ADDR not pulled high)
- Shares I2C bus with BH1750 (0x23) — no address conflict ✅
- Temperature accuracy: ±0.3°C | Humidity accuracy: ±2% RH

---

## Earth Sensor SucuFer — Port B1

```
Grove Cable (B1)          M5Stack Earth Sensor
─────────────────────────────────────────────────
Black  (GND)    ──────►  GND
Red    (VCC 5V) ──────►  VCC
White  (G35)    ──────►  AOUT  (analog output)
Yellow (G25)    ──────►  DOUT  (digital threshold output)
```

- Analog read on **G25** (ADC1_CH8)
- Analog range: 0–4095 (12-bit ADC)
- Calibration required: measure raw value at dry soil and saturated soil

---

## Earth Sensor SucuRod — Port B2

```
Grove Cable (B2)          M5Stack Earth Sensor
─────────────────────────────────────────────────
Black  (GND)    ──────►  GND
Red    (VCC 5V) ──────►  VCC
White  (G36)    ──────►  AOUT  (analog — G36 is INPUT ONLY) ✅
Yellow (G26)    ──────►  DOUT  (digital threshold output)
```

> **⚠️ G36 is input-only on ESP32.** Only use for reading analog values. Never configure as output.

---

## Relay SucuFer (→ Pump SucuFer) — Port C1

```
Grove Cable (C1)          M5Stack Mini Relay 1
──────────────────────────────────────────────────
Black  (GND)    ──────►  GND
Red    (VCC 5V) ──────►  VCC
Yellow (G14)    ──────►  IN   (signal — HIGH = relay ON)

Relay 1 Contacts          Pump 1
──────────────────────────────────────────────────
COM             ──────►  +12V (from DC adapter)
NO              ──────►  Pump 1 (+) red wire
(GND common shared with pump GND)
```

---

## Relay SucuRod (→ Pump SucuRod) — Port C2

```
Grove Cable (C2)          M5Stack Mini Relay 2
──────────────────────────────────────────────────
Black  (GND)    ──────►  GND
Red    (VCC 5V) ──────►  VCC
Yellow (G17)    ──────►  IN   (signal — HIGH = relay ON)

Relay 2 Contacts          Pump 2
──────────────────────────────────────────────────
COM             ──────►  +12V (from DC adapter)
NO              ──────►  Pump 2 (+) red wire
(GND common shared with pump GND)
```

---

## XKC-Y25-V Water Level Sensor

```
DFRobot Driver Board      Station-485
──────────────────────────────────────────────────
VCC             ──────►  5V (USB-A output)
GND             ──────►  GND
OUT             ──────►  GPIO (TBD — confirm port)

Sensor probe    ──────►  Stick to outside of water reservoir (plastic)
```

- Output: HIGH = water present at sensor position, LOW = empty
- Sensitivity: adjustable via SET button on driver board (4 levels)
- For plastic containers ≤ 3mm wall thickness

---

## Power Distribution

```
12V 2A DC Adapter (5.5x2.1mm barrel)
        │
        └──► PWR485 (Station-485 power input)
                │
                ├── Regulates to 5V for Grove ports (internal)
                ├── Regulates to 3.3V for ESP32 core (internal)
                │
                ├── Relay 1 COM ──► Pump 1 (+)
                └── Relay 2 COM ──► Pump 2 (+)

GND rail (common):
    DC adapter GND ──► Station-485 GND ──► Pump 1 (-) ──► Pump 2 (-)

Recommended: 1N4007 flyback diode across each pump (cathode to +12V, anode to GND)
Recommended: 10µF electrolytic capacitor across power rails near relays
```

---

## I2C Bus Summary (Ports A1 + A2 — shared G32/G33)

| Device | Address | Port |
|---|---|---|
| BH1750 | 0x23 | A1 |
| SHT30 outdoor | 0x44 | A2 |

No address conflict. Both respond on the same SDA/SCL lines. ✅

---

## GPIO Summary

| GPIO | Function | Direction | Port |
|---|---|---|---|
| G32 | I2C SDA | I/O | A1 + A2 |
| G33 | I2C SCL | I/O | A1 + A2 |
| G25 | Earth Sensor SucuFer analog | INPUT | B1 |
| G35 | Earth Sensor SucuFer digital | INPUT | B1 |
| G26 | Earth Sensor SucuRod analog | INPUT | B2 |
| G36 | Earth Sensor SucuRod digital (input only) | INPUT | B2 |
| G14 | Relay 1 control | OUTPUT | C1 |
| G17 | Relay 2 control | OUTPUT | C2 |
| TBD | XKC-Y25 signal | INPUT | — |

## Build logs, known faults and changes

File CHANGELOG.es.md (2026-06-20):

# Changelog

Todos los cambios notables a SniperStation serán documentados en este archivo.
Formato basado en [Keep a Changelog](https://keepachangelog.com/en/1.0.0/).

---

## [Sin publicar]

### Agregado
- Sitio de docs publicado (MkDocs Material) en `https://snipermqtt.uzc/station/` detrás de nginx con auth básica; `mkdocs.yml` + `scripts/gen_mkdocs.py` (generador de nav EN/ES) + `scripts/build-docs.sh` (build y deploy)

### Seguridad
- `.gitignore` ahora excluye `.iot`, `secrets.h`, `secrets.env` — evita commitear credenciales WiFi/MQTT

### Planificado
- Firmware Station-485 (Fase 2)
- Firmware CYD ESP32-2432S028 interior x2 (Fase 2)
- Firmware TimerCam X — captura timelapse + HTTP upload + evento MQTT (Fase 2)
- Stack de software Proxmox LXC incluyendo endpoint para fotos + panel Grafana (Fase 3)
- Rediseño + impresión carcasa interior para el CYD (Fase 1)

## [0.6.0] — 2026-03-27

### Agregado
- LXC `snipermqtt.uzc` aprovisionado (VMID 112, Debian 12, 192.168.0.79) en Proxmox
- Mosquitto 2.0.11 — auth activado (`allow_anonymous false`), un usuario por dispositivo, ACL por topic
- InfluxDB 2.8 — org `sniperstation`, bucket `sniperstation`, token escritura (Telegraf) + token lectura (Grafana)
- Telegraf 1.38 — bridge MQTT → InfluxDB como suscriptor
- Grafana 12.4.2 — datasource InfluxDB configurado, contraseña admin cambiada, registro deshabilitado
- nginx — proxy inverso HTTPS para Grafana + endpoint `/upload` para fotos TimerCam, TLS via pfSense CA
- Bot de Telegram (`software/telegram_bot/`) — desplegado como servicio systemd en snipermqtt LXC
  - Consultas en lenguaje natural via agente LLM (Claude o Ollama, seleccionable via `LLM_BACKEND`)
  - Comandos: `/start`, `/estado`/`/status`, `/riego`/`/water`, `/foto`/`/photo`, `/lang`
  - Suscriptor MQTT LWT — alerta por Telegram cuando un dispositivo se desconecta
  - Reportes por email via Resend: diario x3, semanal x1, mensual x1
  - Bilingüe EN/ES — cambiable en tiempo real con `/lang en|es`, persiste en disco
  - Menú de comandos Telegram se actualiza dinámicamente al cambiar idioma
- `software/telegram_bot/agent.py` — loop agéntico multi-LLM (Claude Haiku / Ollama)
- `software/telegram_bot/tools.py` — herramientas de consulta InfluxDB para todos los sensores
- `software/telegram_bot/reports.py` — generación de reportes por email via Resend
- `software/telegram_bot/sniperstation-bot.service` — unidad systemd con secretos via EnvironmentFile
- Hook global en Claude Code: verificación de calidad en archivos Python antes de escribir (sin imports muertos, sin toy code, strings EN/ES, comentarios en inglés)

### Infraestructura
- Secretos almacenados en `/etc/sniperstation/secrets.env` (chmod 600) en la LXC
- Certificados TLS de la CA interna de pfSense desplegados en `/etc/sniperstation/certs/`
- Nesting habilitado en LXC (`features: nesting=1`) para soporte de namespaces de Grafana
- Directorios de fotos creados: `/var/sniperstation/photos/sucufer/` y `sucurod/`

---

## [0.5.0] — 2026-03-26

### Cambiado
- Carpeta del proyecto renombrada: `sucustation/` → `sniperstation/`
- Documento principal renombrado: `sucustation_project.md` → `sniperstation_project.md`

### Agregado
- M5Stack ESP32 PSRAM Timer Camera X (OV3660, 3MP) — pedida, una unidad cubre el área de los materos
- Topics MQTT: `sniperstation/camaras/sucufer/captura` y `sucurod/captura` para eventos de foto
- Almacenamiento de fotos timelapse planificado: HTTP POST desde TimerCam → Proxmox LXC → `photos/sucufer/YYYY-MM-DD_HH.jpg`
- Panel Grafana planificado: última foto por planta
- Comando Telegram planificado: `/foto sucufer` envía la última foto
- Buck converter LM2596 ajustable (con display voltímetro) — alimenta TimerCam X desde el rail de 12V
- Wago 221-415 lever nuts (x2) — distribución del rail +12V y GND sin soldadura
- Nuevo archivo `hardware/schematics/outdoor_power.md` — diagrama completo de distribución de poder outdoor

### Decisiones
- TimerCam X (OV3660 3MP) en vez de ESP32-CAM genérico (OV2640 2MP): hardware dedicado para timelapse, batería + RTC integrados, mismo ecosistema M5Stack
- FOV 66.5° confirmado suficiente para cubrir ambos materos con una sola cámara
- Subida de fotos via HTTP POST (no MQTT): fotos muy grandes para MQTT — MQTT solo para notificación de captura
- Deep sleep por defecto cada 4h (configurable via NVS)
- LM2596 ajustable elegido sobre versión fija 5V: display voltímetro integrado elimina necesidad de multímetro
- Wago 221-415 sobre empalme directo o borneras: más fácil, sin soldadura, reutilizable

---

## [0.4.0] — 2026-03-26

### Cambiado
- Proyecto renombrado: **SucuStation → SniperStation**
- `matero1` renombrado a **SucuFer** (suculenta de Fernanda, sembrada el 22 de abril de 2024, 10 años)
- `matero2` renombrado a **SucuRod** (suculenta de Rodrigo, sembrada el 22 de abril de 2024, 6 años)
- Todos los topics MQTT actualizados: `sucustation/` → `sniperstation/`, `matero1` → `sucufer`, `matero2` → `sucurod`
- Directorio firmware renombrado: `esp8266_interior/` → `cyd_indoor/`

### Agregado
- Proyecto bilingüe EN/ES — todos los documentos disponibles en ambos idiomas (archivos .md y .es.md separados)
- Selección de idioma por dispositivo (CYD y Station-485), guardada en NVS flash, predeterminado inglés
- Strings bilingüe en firmware via `strings.h` con arrays `STR_xxx[2]`
- Vista detalle SucuFer: foto de Fernanda como fondo + humedad suelo + edad de la planta desde el 22/04/2024
- Vista detalle SucuRod: foto de Rodrigo como fondo + humedad suelo + edad de la planta desde el 22/04/2024
- Directorio `assets/photos/` con fotos originales del día de siembra (Fernanda_sucu.jpeg, Rodrigo_sucu.jpeg)

### Decisiones
- Nombres de plantas son personales — Fernanda (10) y Rodrigo (6) sembraron sus suculentas el mismo día
- Fotos de cada niño con su planta usadas como fondo del CYD en la vista de detalle
- Edad de la planta calculada dinámicamente desde la fecha de siembra (22/04/2024) usando reloj NTP

---

## [0.3.0] — 2026-03-26

### Cambiado
- Hardware unidad interior reemplazado: ESP8266 + OLED SSH1106 + TTP223 → **CYD ESP32-2432S028** (todo en uno)
- Firmware interior cambiado a librería TFT_eSPI (antes era U8g2)
- Rediseño de carcasa 3D requerido para el form factor del CYD (marco de pared simple)

### Agregado
- UI multi-vista planificada: screensaver → vista principal (todos los cuartos) → vista detalle (toca una planta)
- CYD suscribe a todos los topics MQTT → muestra exterior + ambos cuartos interiores + suelo + bombas en una pantalla
- Navegación táctil entre vistas (touch resistivo XPT2046, integrado)

### Decisiones
- CYD ESP32-2432S028 sobre ESP8266 + OLED + TTP223: pantalla color táctil, todo en uno, carcasa más simple, UI más rica
- Librería: TFT_eSPI (estándar para CYD, bien documentado)
- ESP8266 x2 y TTP223 x2 liberados de vuelta al inventario

---

## [0.2.0] — 2026-03-25

### Cambiado
- Arquitectura unidad interior expandida de 1 a **2 unidades** (Master Bedroom + Kids Bedroom)
- Unidad ESP8266 interior mejorada: se agregó pantalla OLED SSH1106 1.3" + sensor TTP223 por unidad
- Topics MQTT actualizados: `sniperstation/interior/temperatura` → `sniperstation/interior/{master|kids}/temperatura|humedad`

### Agregado
- Modelo OpenSCAD de carcasa: `hardware/enclosure/indoor_unit.scad` — paramétrico, dos piezas (shell + back plate), montaje en pared con keyhole, salida USB por abajo
- Comportamiento display OLED: screensaver (logo, tenue) → toque → activo (datos, brillante) → timeout 30s
- Lógica de brillo adaptivo: screensaver 10/255, activo 200/255, modo nocturno 00–06h apagado
- Sincronización NTP (pool.ntp.org, America/New_York) — fecha/hora mostrada en display activo
- Sensor táctil TTP223 para despertar display desde screensaver
- OLED SSH1106 1.3" agregado al BOM como pendiente de compra (pack de 2 HiLetgo)
- Carcasa interior (x2) agregada al BOM

### Decisiones
- OLED SSH1106 1.3" sobre SSD1306 0.96" — mejor visibilidad del logo
- Librería SSH1106: U8g2 (soporte nativo SH1106)
- TTP223 del inventario como interfaz táctil
- SHT30 montado en la parte superior de la carcasa 3D usando su casing plástico con ranuras de ventilación

---

## [0.1.0] — 2026-03-25

### Agregado
- Diseño y arquitectura completa del proyecto documentados en `sucustation_project.md`
- Hardware finalizado: M5Stack Station-485, SHT30 x2, BH1750, Earth Sensors x2, XKC-Y25, bombas peristálticas x2, módulos relay x2, ESP8266 NodeMCU
- Esquema de topics MQTT definido
- Lógica de riego diseñada (ciclo 6h, condicionado por suelo/humedad/nivel agua)
- Paneles dashboard Grafana planificados
- Tipos de alertas Telegram definidos
- Inventario completo catalogado (kit SunFounder + componentes adicionales)
- Estructura de documentación del proyecto creada (README, ROADMAP, TODO, CHANGELOG, hardware/)
- Lista de materiales — `hardware/BOM.md`
- Diagramas de conexión — `hardware/schematics/`
- Referencias de datasheets — `hardware/datasheets/SOURCES.md`

### Decisiones
- Bomba peristáltica sobre sumergible (precisión para suculentas)
- Un recipiente grande compartido para las dos bombas
- Sensor de nivel de agua capacitivo (XKC-Y25, sin partes móviles)
- Station-485 afuera con los materos (cables cortos)
- ESP8266 adentro para SHT30 interior (sin cables atravesando paredes)
- Proxmox LXC para el stack de software (infraestructura existente)
- SHT30 genérico en vez de ENV III M5Stack (sin stock, mismo chip)

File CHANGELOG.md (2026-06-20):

# Changelog

All notable changes to SniperStation will be documented in this file.
Format based on [Keep a Changelog](https://keepachangelog.com/en/1.0.0/).

---

## [Unreleased]

### Added
- Published docs site (MkDocs Material) at `https://snipermqtt.uzc/station/` behind nginx basic auth; `mkdocs.yml` + `scripts/gen_mkdocs.py` (EN/ES nav generator) + `scripts/build-docs.sh` (build & deploy)

### Security
- `.gitignore` now excludes `.iot`, `secrets.h`, `secrets.env` — prevents committing WiFi/MQTT credentials

### Planned
- Station-485 firmware (Phase 2)
- CYD ESP32-2432S028 indoor firmware x2 (Phase 2)
- TimerCam X firmware — timelapse capture + HTTP upload + MQTT event (Phase 2)
- Proxmox LXC software stack including photo storage endpoint + Grafana panel (Phase 3)
- Redesign + print indoor enclosure for CYD form factor (Phase 1)

## [0.6.0] — 2026-03-27

### Added
- Provisioned `snipermqtt.uzc` LXC (VMID 112, Debian 12, 192.168.0.79) on Proxmox
- Mosquitto 2.0.11 — auth enabled (`allow_anonymous false`), one user per device, ACL file per topic
- InfluxDB 2.8 — org `sniperstation`, bucket `sniperstation`, write-only token (Telegraf) + read-only token (Grafana)
- Telegraf 1.38 — MQTT subscriber bridge → InfluxDB
- Grafana 12.4.2 — InfluxDB datasource configured, admin password changed, sign-up disabled
- nginx — HTTPS reverse proxy for Grafana + `/upload` endpoint for TimerCam photos, TLS via pfSense CA
- Telegram bot (`software/telegram_bot/`) — deployed as systemd service on snipermqtt LXC
  - Natural language queries via LLM agent (Claude or Ollama, selectable via `LLM_BACKEND`)
  - Commands: `/start`, `/estado`/`/status`, `/riego`/`/water`, `/foto`/`/photo`, `/lang`
  - MQTT LWT subscriber — sends Telegram alert when any device goes offline
  - Scheduled email reports via Resend: daily x3, weekly x1, monthly x1
  - Bilingual EN/ES — switchable at runtime via `/lang en|es`, persisted to disk
  - Dynamic Telegram command menu updates on language switch
- `software/telegram_bot/agent.py` — multi-LLM agentic loop (Claude Haiku / Ollama)
- `software/telegram_bot/tools.py` — InfluxDB query tools for all sensor data
- `software/telegram_bot/reports.py` — email report generation via Resend
- `software/telegram_bot/sniperstation-bot.service` — systemd unit with secrets via EnvironmentFile
- Global Claude Code hook: pre-write Python file quality checks (no unused imports, no toy code, EN/ES strings, English comments)

### Infrastructure
- All secrets stored in `/etc/sniperstation/secrets.env` (chmod 600) on snipermqtt LXC
- TLS certificates from pfSense internal CA deployed to `/etc/sniperstation/certs/`
- LXC nesting enabled (`features: nesting=1`) to support Grafana systemd namespace requirements
- Photo storage directories: `/var/sniperstation/photos/sucufer/` and `sucurod/`

---

## [0.5.0] — 2026-03-26

### Changed
- Project folder renamed: `sucustation/` → `sniperstation/`
- Project document renamed: `sucustation_project.md` → `sniperstation_project.md`

### Added
- M5Stack ESP32 PSRAM Timer Camera X (OV3660, 3MP) — ordered, one unit covering planters area
- MQTT topics: `sniperstation/camaras/sucufer/captura` and `sucurod/captura` for photo events
- Timelapse photo storage planned: HTTP POST from TimerCam → Proxmox LXC → `photos/sucufer/YYYY-MM-DD_HH.jpg`
- Grafana panel planned: latest photo per plant
- Telegram command planned: `/foto sucufer` sends latest photo
- Phase 3 task: Python/Flask HTTP endpoint to receive photos on Proxmox LXC

### Decisions
- TimerCam X (OV3660 3MP) over generic ESP32-CAM (OV2640 2MP): dedicated timelapse hardware, built-in battery + RTC, same M5Stack ecosystem
- Photo upload via HTTP POST (not MQTT): photos too large for MQTT — MQTT only used for capture event notification
- Deep sleep cycle default: every 4h (configurable via NVS)
- FOV 66.5° confirmed sufficient to cover both planters with a single camera unit
- LM2596 buck converter (adjustable, built-in voltmeter display) to power TimerCam X from 12V rail — Station-485 USB-A already reserved for XKC-Y25
- Wago 221-415 lever nuts (x2) for +12V and GND distribution rails — no soldering required
- Created `hardware/schematics/outdoor_power.md` as dedicated outdoor power distribution diagram

---

## [0.4.0] — 2026-03-26

### Changed
- Project renamed: **SucuStation → SniperStation**
- `matero1` renamed to **SucuFer** (Fernanda's succulent, planted April 22, 2024, age 10)
- `matero2` renamed to **SucuRod** (Rodrigo's succulent, planted April 22, 2024, age 6)
- All MQTT topics updated: `sucustation/` → `sniperstation/`, `matero1` → `sucufer`, `matero2` → `sucurod`
- Firmware directory renamed: `esp8266_interior/` → `cyd_indoor/`

### Added
- SucuFer detail view: Fernanda's photo as background + soil moisture + plant age since April 22, 2024
- SucuRod detail view: Rodrigo's photo as background + soil moisture + plant age since April 22, 2024
- `assets/photos/` directory planned for plant photos (CYD display backgrounds)

### Decisions
- Plant names are personal — Fernanda (10) and Rodrigo (6) each planted their succulent on the same day
- Photos of each child with their plant used as CYD background in detail view
- Plant age calculated dynamically from planting date (April 22, 2024) using NTP clock

---

## [0.2.0] — 2026-03-25

### Changed
- Indoor unit architecture expanded from 1 to **2 units** (Master Bedroom + Kids Bedroom)
- ESP8266 indoor unit upgraded: added OLED SSH1106 1.3" display + TTP223 touch sensor per unit
- MQTT topics updated: `sucustation/interior/temperatura` → `sucustation/interior/{master|kids}/temperatura|humedad`

### Added
- Bilingual EN/ES support — all documents available in both languages (separate .md and .es.md files)
- Per-device language selection (CYD + Station-485), stored in NVS flash, default English
- Bilingual firmware strings via `strings.h` with `STR_xxx[2]` arrays
- OpenSCAD enclosure model: `hardware/enclosure/indoor_unit.scad` — parametric, two pieces (shell + back plate), keyhole wall mount, USB bottom exit
- OLED display behavior: screensaver (logo, dim) → touch → active (data, bright) → 30s timeout
- Adaptive brightness logic: screensaver 10/255, active 200/255, night mode 00–06h display off
- NTP time sync (pool.ntp.org, America/New_York) — date/time shown on active display
- TTP223 capacitive touch sensor to wake display from screensaver
- 3D printed indoor enclosure planned (ESP8266 + OLED + TTP223 + SHT30 exposed top)
- OLED SSH1106 1.3" added to BOM pending purchase (HiLetgo pack of 2)
- Indoor enclosure (x2) added to BOM

### Decisions
- OLED SSH1106 1.3" over 0.96" SSD1306 — better logo visibility
- SSH1106 library: U8g2 (native SH1106 support)
- TTP223 from inventory as touch interface (replaces touchscreen OLED, same UX)
- SHT30 mounts on top of 3D enclosure using its built-in plastic casing with ventilation slots

---

## [0.3.0] — 2026-03-26

### Changed
- Indoor unit hardware replaced: ESP8266 + OLED SSH1106 + TTP223 → **CYD ESP32-2432S028** (all-in-one)
- Indoor firmware target changed to TFT_eSPI library (was U8g2)
- 3D enclosure redesign required for CYD form factor (simpler wall frame vs multi-component box)

### Added
- Multi-view UI planned: screensaver → main view (all rooms) → detail view (tap a room)
- CYD subscribes to all MQTT topics → shows exterior + both indoor rooms + soil + pumps on one screen
- Touch navigation between views (resistive XPT2046, integrated)

### Decisions
- CYD ESP32-2432S028 over ESP8266 + OLED + TTP223: color touchscreen, all-in-one, simpler enclosure, richer UI
- Library: TFT_eSPI (standard for CYD, well documented)
- ESP8266 x2 and TTP223 x2 freed back to inventory

---

## [0.1.0] — 2026-03-25

### Added
- Full project design and architecture documented in `sucustation_project.md` (planning session)
- Hardware selection finalized: M5Stack Station-485, SHT30 x2, BH1750, Earth Sensors x2, XKC-Y25, peristaltic pumps x2, relay modules x2, ESP8266 NodeMCU
- MQTT topic schema defined
- Irrigation logic designed (6h cycle, soil/humidity/water-level gating)
- Grafana dashboard panels planned (7 panels)
- Telegram alert types defined
- Full inventory catalogued (SunFounder kit + additional components)
- Project documentation structure created (README, ROADMAP, TODO, CHANGELOG, hardware/)
- Bill of Materials — `hardware/BOM.md`
- Wiring diagrams — `hardware/schematics/`
- Datasheet references — `hardware/datasheets/SOURCES.md`

### Decisions
- Peristaltic pump over submersible (precision for succulents)
- Single shared water reservoir for both pumps
- Capacitive water level sensor (XKC-Y25, no moving parts)
- Station-485 outdoors with planters (short cable runs)
- ESP8266 indoors for interior SHT30 (no wall penetration needed for main controller)
- Proxmox LXC for software stack (existing infrastructure)
- SHT30 generic instead of M5Stack ENV III (out of stock, same chip)

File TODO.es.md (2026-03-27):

# SniperStation — TODO

## Pendiente Comprar

- [x] ~~Adaptador DC 12V 2A, conector barrel 5.5mm~~ — pedido ✅
- [ ] Caja weatherproof outdoor — IP65 mínimo, con ranuras de ventilación o soporte para fan (Amazon)
- [x] ~~Cable Grove↔Dupont HY2.0-4P a 2.54mm female 20cm~~ — pedido ✅
- [x] ~~Buck converter DC-DC LM2596 (ajustable, display voltímetro integrado)~~ — pedido ✅
- [x] ~~OLED SSH1106 1.3" I2C 128x64~~ — reemplazado por CYD ESP32-2432S028 (todo en uno)
- [x] ~~Wago 221-415 lever nuts (5-port) x2~~ — pedidos ✅
- [x] ~~M5Stack ESP32 PSRAM Timer Camera X (OV3660)~~ — pedida ✅
- [x] ~~LM2596 buck converter x2 (ajustable, display voltímetro)~~ — pedidos ✅

## Hardware — Sin Resolver

- [ ] **Confirmar GPIO para señal OUT del XKC-Y25** — puertos B1 y B2 usados por sensores de suelo, C1 y C2 por relays. Opciones: usar un GPIO expuesto directamente o reasignar un sensor. Documentar decisión final en `hardware/schematics/station485_wiring.md`.

## Unidades Interiores — Diseño Pendiente

- [ ] Rediseñar carcasa 3D para CYD ESP32-2432S028 (marco de pared simple, ventana pantalla 2.8" + slot SHT30 arriba)
  - [ ] Medir board CYD cuando llegue
  - [ ] Actualizar indoor_unit.scad para nuevo form factor
  - [ ] **BLOQUEADO: medir casing real del SHT30** — cuando llegue el pedido
  - [ ] Exportar STL y mandar a imprimir x2
- [ ] Buscar servicio de impresión 3D económico (local u online — JLCPCB, Treatstock, biblioteca local, etc.)
- [ ] Imprimir x2 (master bedroom + kids bedroom)

## Documentación

- [ ] Traducir documentos hardware al español:
  - [ ] `hardware/BOM.es.md`
  - [ ] `hardware/schematics/station485_wiring.es.md`
  - [ ] `hardware/schematics/esp8266_interior.es.md`
  - [ ] `hardware/schematics/system_overview.es.md`
  - [ ] `hardware/enclosure/indoor_unit_design.es.md`
  - [ ] `hardware/enclosure/requirements.es.md`
- [ ] Agregar esquemáticos Fritzing o KiCad a `hardware/schematics/` una vez confirmada la asignación de GPIO
- [ ] Agregar PDFs de datasheets a `hardware/datasheets/` (actualmente solo URLs en SOURCES.md)

## Fase 1 — Hardware (no iniciado)

- [ ] Bench test I2C BH1750 (dirección esperada 0x23)
- [ ] Bench test I2C SHT30 (dirección esperada 0x44)
- [ ] Verificar sin conflicto de direcciones I2C en bus A1/A2
- [ ] Bench test lecturas analógicas Earth Sensor (valores ADC en seco/mojado)
- [ ] Bench test salida digital XKC-Y25 (HIGH/LOW con agua / sin agua)
- [ ] Prueba actuación relay + giro bomba a 12V
- [ ] Verificar presupuesto de energía: medir consumo real a 12V con sensores + 1 bomba activa

## Fase 2 — Firmware (no iniciado)

- [ ] Firmware Station-485 (ver ROADMAP Fase 2)
- [ ] Firmware CYD indoor (ver ROADMAP Fase 2)

## Fase 3 — Software (en progreso)

- [x] ~~Provisionar LXC en Proxmox~~ — snipermqtt.uzc 192.168.0.79 ✅
- [x] ~~Mosquitto 2.0.11~~ — auth + ACL, un usuario por dispositivo ✅
- [x] ~~InfluxDB 2.8~~ — org+bucket `sniperstation`, tokens escritura/lectura ✅
- [x] ~~Telegraf 1.38~~ — bridge MQTT → InfluxDB ✅
- [x] ~~Grafana 12.4.2~~ — datasource configurado, HTTPS via nginx + pfSense CA ✅
- [x] ~~Bot Telegram~~ — agente NL (Claude/Ollama), comandos, alertas LWT, reportes email, EN/ES ✅
- [ ] Dashboard Grafana — 7 paneles (esperando datos reales del ESP32)
- [ ] Endpoint HTTP para fotos TimerCam X
- [ ] Almacenamiento fotos: `photos/sucufer/YYYY-MM-DD_HH.jpg`
- [ ] Panel Grafana: última foto por planta
- [ ] 2FA (TOTP) en cuenta admin Grafana
- [ ] fail2ban para Mosquitto y Grafana

## Decisiones Pendientes

- [ ] Definir lógica de cooldown: tiempo mínimo entre ciclos de riego para evitar re-regar muy pronto
- [x] ~~Elegir librería bot Telegram~~ — python-telegram-bot 22.7 ✅
- [ ] Definir diseño del logo bitmap + layout UI para pantalla TFT CYD (screensaver + vista principal + vista detalle)
- [ ] Fotos actualizadas de Fernanda y Rodrigo con sus suculentas (las actuales del día de siembra serán reemplazadas)

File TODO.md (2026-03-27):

# SniperStation — TODO

## Pending Purchase

- [x] ~~DC adapter 12V 2A, 5.5mm barrel jack~~ — ordered ✅
- [x] ~~DC-DC buck converter LM2596 (x2, adjustable, built-in voltmeter)~~ — ordered ✅
- [x] ~~Wago 221-415 lever nuts (5-port) x2~~ — ordered ✅
- [ ] Outdoor weatherproof enclosure — IP65 minimum, with ventilation slots or fan mount (Amazon)
- [x] ~~Grove↔Dupont cable HY2.0-4P to 2.54mm female 20cm~~ — ordered ✅
- [x] ~~OLED SSH1106 1.3" I2C 128x64~~ — replaced by CYD ESP32-2432S028 (all-in-one)

---

## Phase 1 — Hardware Assembly

### Hardware Tasks
- [ ] Bench test BH1750 I2C scan (expected address 0x23)
- [ ] Bench test SHT30 I2C scan (expected address 0x44)
- [ ] Verify no I2C address conflict on shared A1/A2 bus
- [ ] Bench test Earth Sensor analog reads (raw ADC values at dry/wet)
- [ ] Bench test XKC-Y25 digital output (HIGH/LOW at water/no-water)
- [ ] Test relay actuation + pump spin at 12V
- [ ] Verify power budget: measure actual draw at 12V with all sensors + 1 pump active
- [ ] **Confirm GPIO port for XKC-Y25 signal OUT** — ports B1/B2 used by Earth Sensors, C1/C2 by relays. Document in `hardware/schematics/station485_wiring.md`

### TimerCam X
- [ ] Test TimerCam X WiFi + photo capture (bench test when received)
- [ ] Decide mounting position: one camera covering both planters vs one per planter
- [ ] Confirm 5V power source for outdoor installation
- [ ] Design acrylic or glass window cutout in IP65 enclosure for camera lens

### Indoor Units
- [ ] Redesign 3D enclosure for CYD ESP32-2432S028 (wall frame, 2.8" screen window + SHT30 slot on top)
  - [ ] Measure CYD board dimensions when received
  - [ ] Update `indoor_unit.scad` for new form factor
  - [ ] **BLOCKED:** measure real SHT30 casing — wait for delivery
  - [ ] Export STL and send to print x2
- [ ] Find affordable 3D print service (JLCPCB, Treatstock, local library)
- [ ] Print x2 (master bedroom + kids bedroom)

### Security — Phase 1
- [ ] Source IP65 enclosure with **Torx or hexalobe screws** — not Phillips
- [ ] Purchase **cable glands PG7/PG9** (one per cable exiting outdoor enclosure)
- [ ] CYD 3D enclosure design must block access to EN (reset) button
- [ ] Document MAC address of each ESP32 → `hardware/inventory.md`

---

## Phase 2 — Firmware

### Firmware Tasks
- [ ] Station-485 firmware (see ROADMAP Phase 2 for full spec)
- [ ] CYD ESP32-2432S028 indoor firmware (see ROADMAP Phase 2 for full spec)
- [ ] TimerCam X firmware (see ROADMAP Phase 2 for full spec)

### Security — Phase 2
- [ ] **Before first firmware commit:** add `secrets.h` entries to `.gitignore`
  - `firmware/station485/secrets.h`
  - `firmware/cyd_indoor/secrets.h`
  - `firmware/timercam/secrets.h`
- [ ] Create `secrets.h.example` with placeholder values for each firmware
- [ ] Implement watchdog timer (30s) in all ESP32 firmware
- [ ] Implement relay absolute max duration (60s force-off) in Station-485
- [ ] Sanitize MQTT pump commands: accept only `'0'`/`'1'`, length == 1
- [ ] Configure LWT on all devices (`sniperstation/sistema/lwt` → `offline`)
- [ ] Persist pump state in NVS — force relay OFF on reboot if pump was active
- [ ] Set OTA password on all ESP32

---

## Phase 3 — Software Stack

### Software Tasks
- [x] ~~Provision LXC container (Debian 12) on Proxmox~~ — snipermqtt.uzc 192.168.0.79 ✅
- [x] ~~Install and configure Mosquitto broker~~ — auth + ACL, port 1883 ✅
- [x] ~~Install and configure InfluxDB 2.x (org, bucket, tokens)~~ — org+bucket `sniperstation`, write/read tokens ✅
- [x] ~~MQTT → InfluxDB bridge (Telegraf or Python)~~ — Telegraf 1.38 ✅
- [x] ~~Install and configure Grafana (dashboard, datasource)~~ — datasource configured, awaiting real data for dashboard ✅
- [x] ~~Telegram bot (BotFather, alerts, manual irrigation command)~~ — deployed with NL agent, LWT alerts, /lang EN/ES ✅
- [ ] Grafana dashboard — 7 panels (waiting for ESP32 data)
- [ ] HTTP endpoint for TimerCam X photo upload
- [ ] Photo storage: `photos/sucufer/YYYY-MM-DD_HH.jpg`
- [ ] Grafana panel: latest photo per plant
- [ ] Telegram command: `/foto sucufer`

### Security — Phase 3
**Network (do before provisioning):**
- [ ] Disable WPS on router
- [ ] No port forwarding for Proxmox UI (8006) to internet
- [ ] Create IoT VLAN 10 (192.168.10.0/24) with firewall rules blocking IoT → LAN
- [ ] Assign static IPs to all ESP32 via DHCP static mappings
- [ ] Static IP for LXC

**Mosquitto:**
- [x] ~~`allow_anonymous false` in `mosquitto.conf`~~ ✅
- [x] ~~Create one user per device (6 users)~~ ✅
- [x] ~~Configure ACL file~~ ✅
- [x] ~~Enable connection logging~~ ✅

**InfluxDB:**
- [x] ~~Create write-only token for Telegraf~~ ✅
- [x] ~~Create read-only token for Grafana~~ ✅
- [x] ~~Never use All Access token in services~~ ✅

**Grafana:**
- [x] ~~Change default `admin:admin` password immediately after install~~ ✅
- [x] ~~Disable sign-up and anonymous access~~ ✅
- [ ] Enable 2FA (TOTP) on admin account
- [ ] Add security monitoring panel (device last seen, pump activations)

**Telegram Bot:**
- [x] ~~Restrict bot to authorized `chat_id` only~~ ✅

**HTTP photo endpoint:**
- [ ] Bearer token authentication on `/upload`
- [x] ~~nginx rate limiting: 10 req/min per IP~~ ✅
- [x] ~~HTTPS with pfSense CA cert~~ ✅

**Secrets & permissions:**
- [x] ~~All secrets in `/etc/sniperstation/secrets.env` with `chmod 600`~~ ✅
- [x] ~~Load secrets via systemd `EnvironmentFile`~~ ✅
- [x] ~~`chmod 600` on Mosquitto passwd and ACL files~~ ✅

**Monitoring:**
- [ ] Install and configure `fail2ban` for Mosquitto and Grafana
- [x] ~~Telegram alert on LWT `offline` message from any device~~ ✅

**MQTTS (after stack is working):**
- [ ] Generate CA + server cert (script in `docs/security.md` §8.2)
- [ ] Configure Mosquitto on port 8883 with TLS 1.2
- [ ] Update all ESP32 firmware with embedded CA cert
- [ ] Update firewall: allow 8883, remove 1883

---

## Phase 4 — Calibration

- [ ] Calibrate Earth Sensors (dry/moist/wet ADC values with real planters)
- [ ] Calibrate pump flow rate at 12V (ml/second)
- [ ] Adjust irrigation duration and thresholds
- [ ] Stress test: full irrigation cycle end-to-end
- [ ] Validate all Telegram alerts

### Security — Phase 4
- [ ] Verify watchdog: simulate hung loop → confirm ESP32 resets
- [ ] Verify relay max duration: send MQTT `'1'` → confirm pump stops at 60s
- [ ] Verify LWT: kill WiFi on Station-485 → confirm Telegram alert fires
- [ ] Verify pump state recovery: cut power mid-pump → confirm relay OFF after reboot

---

## Phase 5 — Deployment

- [ ] Install cable glands on outdoor enclosure, seal with silicone
- [ ] Install Station-485 in outdoor enclosure (shade location mandatory)
- [ ] Route tubing from water reservoir to planters
- [ ] Run 72h unattended monitoring test
- [ ] Document final calibration values in firmware config

### Security — Phase 5
- [ ] Confirm Torx security screws installed on enclosure
- [ ] Confirm all cable glands sealed — no open holes
- [ ] Confirm enclosure is in permanent shade
- [ ] Passive ventilation installed (10mm holes with mesh + rain covers)
- [ ] Final audit: VLAN rules active, MQTTS running, no default passwords, `secrets.h` not in git history

---

## Documentation

- [ ] Translate hardware documents to Spanish:
  - [ ] `hardware/BOM.es.md`
  - [ ] `hardware/schematics/station485_wiring.es.md`
  - [ ] `hardware/schematics/system_overview.es.md`
  - [ ] `hardware/enclosure/indoor_unit_design.es.md`
  - [ ] `hardware/enclosure/requirements.es.md`
- [ ] Add Fritzing or KiCad schematic files once GPIO assignment confirmed
- [ ] Add datasheet PDFs to `hardware/datasheets/`
- [ ] `hardware/inventory.md` — MAC addresses + serial numbers of all ESP32 devices

---

## Simulation & Testing

- [ ] **Wokwi** — simulate Station-485 firmware (ESP32 + BH1750 + SHT30 + relays + MQTT) before hardware arrives
  - [ ] Convert `hardware/schematics/station485_wiring.md` to Wokwi diagram JSON
  - [ ] Simulate irrigation logic with mocked sensor values
  - [ ] Validate MQTT publish/subscribe flow against local broker

---

## Decisions Pending

- [ ] Define cooldown logic: minimum time between irrigation cycles
- [ ] Choose Telegram bot library (python-telegram-bot vs pyTelegramBotAPI)
- [ ] Define logo bitmap + UI layout for CYD display (screensaver + main + detail views)
- [ ] Get updated photos of Fernanda and Rodrigo with their grown succulents

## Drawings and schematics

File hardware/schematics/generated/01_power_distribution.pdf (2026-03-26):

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

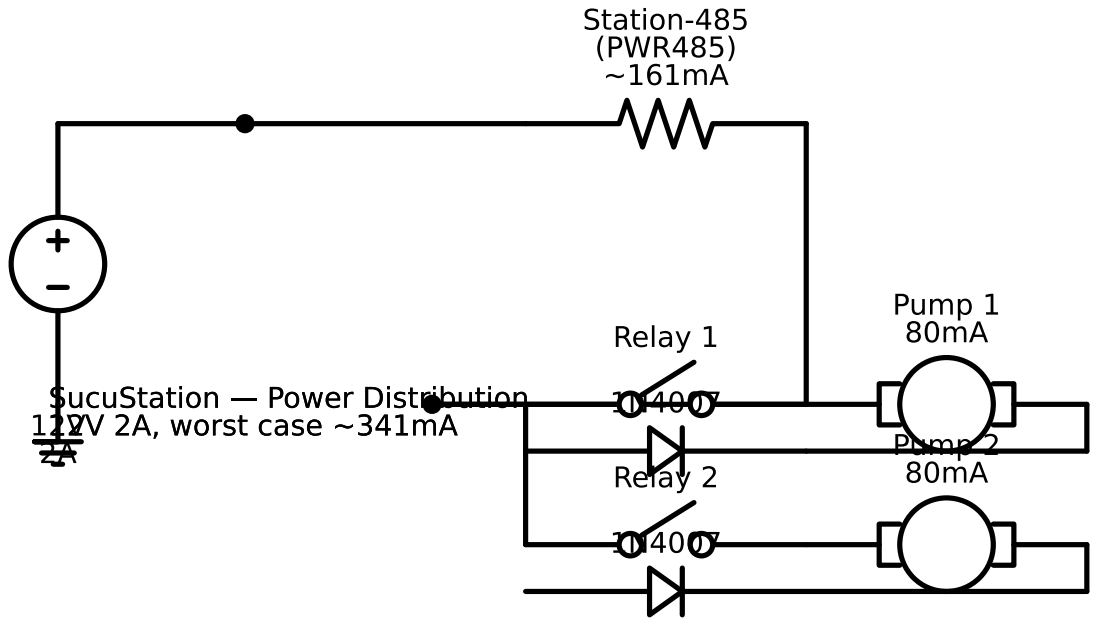
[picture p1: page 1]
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

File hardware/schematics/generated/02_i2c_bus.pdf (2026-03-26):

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

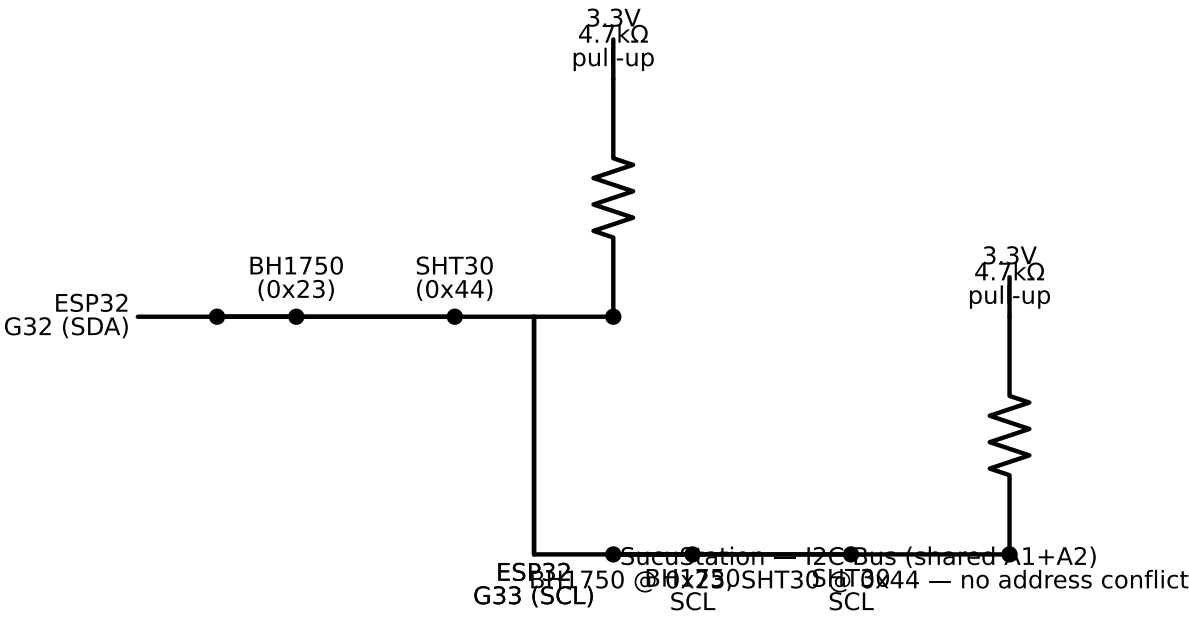
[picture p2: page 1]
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

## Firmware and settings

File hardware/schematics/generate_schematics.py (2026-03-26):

"""
SucuStation — Schematic generator
Generates electrical schematics as SVG and PDF using schemdraw.

Usage:
    python3 generate_schematics.py

Output files are written to ./generated/
"""

import schemdraw
import schemdraw.elements as elm
import matplotlib
matplotlib.use('Agg')  # headless backend, no display required
import matplotlib.pyplot as plt
import os

OUTPUT_DIR = os.path.join(os.path.dirname(__file__), 'generated')
os.makedirs(OUTPUT_DIR, exist_ok=True)


def save(drawing, name):
    """Save drawing as SVG and PDF."""
    svg_path = os.path.join(OUTPUT_DIR, f'{name}.svg')
    pdf_path = os.path.join(OUTPUT_DIR, f'{name}.pdf')
    drawing.save(svg_path)
    drawing.save(pdf_path)
    print(f'  saved: {svg_path}')
    print(f'  saved: {pdf_path}')


# ---------------------------------------------------------------------------
# 1. Power distribution — 12V adapter → Station-485 + Pumps
# ---------------------------------------------------------------------------
def schematic_power():
    print('Generating: power_distribution')
    with schemdraw.Drawing(fontsize=11) as d:
        d.config(inches_per_unit=0.5)

        # 12V source
        V1 = d.add(elm.SourceV().up().label('12V\n2A', loc='left'))
        d.add(elm.Line().right(2))

        # Split to Station-485
        d.add(elm.Dot())
        top_rail = d.add(elm.Line().right(3))

        # Station-485 represented as a box
        d.add(elm.Resistor().right().label('Station-485\n(PWR485)\n~161mA', loc='top'))
        d.add(elm.Line().down())
        d.add(elm.Line().left(4))

        # Back to junction for relay branch
        d.add(elm.Dot())

        # Relay 1 → Pump 1 branch
        d.add(elm.Line().right(1))
        rel1 = d.add(elm.Switch().right().label('Relay 1', loc='top'))
        d.add(elm.Motor().right().label('Pump 1\n80mA', loc='top'))
        d.add(elm.Line().down(0.5))
        p1_gnd = d.add(elm.Line().left(3))

        # Diode flyback across pump 1
        d.add(elm.Diode().left().label('1N4007', loc='top').reverse())

        # Relay 2 → Pump 2 branch
        d.add(elm.Line().down(1.5).at(rel1.start))
        d.add(elm.Switch().right().label('Relay 2', loc='top'))
        d.add(elm.Motor().right().label('Pump 2\n80mA', loc='top'))
        d.add(elm.Line().down(0.5))
        d.add(elm.Line().left(3))
        d.add(elm.Diode().left().label('1N4007', loc='top').reverse())

        # GND symbol
        d.add(elm.Ground().at(V1.start))

        d.add(elm.Label().at(d.here).label('SucuStation — Power Distribution\n12V 2A, worst case ~341mA', loc='right'))

    save(d, '01_power_distribution')


# ---------------------------------------------------------------------------
# 2. I2C bus — BH1750 + SHT30 on shared bus (Ports A1 + A2)
# ---------------------------------------------------------------------------
def schematic_i2c():
    print('Generating: i2c_bus')
    with schemdraw.Drawing(fontsize=11) as d:
        d.config(inches_per_unit=0.5)

        # ESP32 (Station-485) SDA/SCL lines
        d.add(elm.Line().right(1).label('ESP32\nG32 (SDA)', loc='left'))
        sda_start = d.add(elm.Dot())
        d.add(elm.Line().right(5))

        # Pull-up SDA
        d.add(elm.Dot())
        pu_sda = d.add(elm.Resistor().up().label('4.7kΩ\npull-up', loc='right'))
        d.add(elm.Line().up(0.5).label('3.3V', loc='right'))

        # BH1750 on SDA
        d.add(elm.Line().right(1).at(sda_start.end))
        d.add(elm.Dot().label('BH1750\n(0x23)', loc='top'))

        # SHT30 on SDA
        d.add(elm.Line().right(3).at(sda_start.end))
        d.add(elm.Dot().label('SHT30\n(0x44)', loc='top'))

        # SCL line below
        d.add(elm.Line().right(1).at(d.here).label('ESP32\nG33 (SCL)', loc='left').down(3))
        d.add(elm.Line().right(1))
        scl_start = d.add(elm.Dot())
        d.add(elm.Line().right(5))

        d.add(elm.Dot())
        d.add(elm.Resistor().up().label('4.7kΩ\npull-up', loc='right'))
        d.add(elm.Line().up(0.5).label('3.3V', loc='right'))

        d.add(elm.Line().right(1).at(scl_start.end))
        d.add(elm.Dot().label('BH1750\nSCL', loc='bottom'))

        d.add(elm.Line().right(3).at(scl_start.end))
        d.add(elm.Dot().label('SHT30\nSCL', loc='bottom'))

        d.add(elm.Label().label('SucuStation — I2C Bus (shared A1+A2)\nBH1750 @ 0x23, SHT30 @ 0x44 — no address conflict', loc='bottom'))

    save(d, '02_i2c_bus')


# ---------------------------------------------------------------------------
# 3. ESP8266 indoor — SHT30 with I2C pull-ups
# ---------------------------------------------------------------------------
def schematic_esp8266():
    print('Generating: esp8266_indoor')
    with schemdraw.Drawing(fontsize=11) as d:
        d.config(inches_per_unit=0.5)

        # 3V3 rail
        d.add(elm.Line().right(0.5).label('ESP8266\n3V3', loc='left'))
        d.add(elm.Dot())
        vcc = d.here

        # VCC to SHT30
        d.add(elm.Line().right(4))
        d.add(elm.Dot().label('SHT30\nVCC (red)', loc='right'))

        # Pull-up SDA
        d.add(elm.Line().down(1).at(vcc))
        d.add(elm.Dot())
        puda = d.here
        d.add(elm.Resistor().down().label('10KΩ', loc='right'))
        # SDA line
        d.add(elm.Dot())
        d.add(elm.Line().left(0.5).label('D2 (GPIO4)\nSDA', loc='left'))
        d.add(elm.Line().right(4).at(d.here))
        d.add(elm.Dot().label('SHT30\nSDA (white)', loc='right'))

        # Pull-up SCL
        d.add(elm.Line().down(1).at(puda))
        d.add(elm.Resistor().down().label('10KΩ', loc='right'))
        d.add(elm.Dot())
        d.add(elm.Line().left(0.5).label('D1 (GPIO5)\nSCL', loc='left'))
        d.add(elm.Line().right(4).at(d.here))
        d.add(elm.Dot().label('SHT30\nSCL (yellow)', loc='right'))

        # GND
        d.add(elm.Line().down(1).at(d.here))
        d.add(elm.Line().left(4))
        d.add(elm.Dot().label('SHT30\nGND (black)', loc='left'))
        d.add(elm.Line().left(0.5).label('ESP8266\nGND', loc='left'))

        d.add(elm.Label().label('SucuStation — ESP8266 Indoor Unit\nSHT30 @ I2C 0x44, 10KΩ pull-ups on SDA+SCL', loc='bottom'))

    save(d, '03_esp8266_indoor')


# ---------------------------------------------------------------------------
# 4. Relay + pump circuit detail
# ---------------------------------------------------------------------------
def schematic_relay_pump():
    print('Generating: relay_pump_circuit')
    with schemdraw.Drawing(fontsize=11) as d:
        d.config(inches_per_unit=0.5)

        # ESP32 GPIO → relay coil (in1/in2)
        d.add(elm.Line().right(0.5).label('ESP32\nG14 (Relay1)\nor G17 (Relay2)', loc='left'))
        relay = d.add(elm.Relay().right().label('M5Stack\nMini Relay\n3A/30VDC', loc='top'))

        # Switch side: 12V → relay.a (COM), relay.b → pump
        d.add(elm.SourceV().up().reverse().label('12V', loc='left').at(relay.a))
        vcc_top = d.here

        # Wire from 12V top across to pump positive
        d.add(elm.Line().right(2))
        d.add(elm.Dot())
        pump_plus = d.here

        # Pump motor
        d.add(elm.Motor().right().label('Peristaltic\nPump 12V\n~80mA', loc='top'))
        motor_end = d.here

        # Flyback diode across pump (cathode to +, anode to -)
        d.add(elm.Diode().left().label('1N4007\nflyback', loc='top').reverse())
        pump_minus = d.here

        # Wire from relay.b down to pump negative rail
        d.add(elm.Line().down().at(relay.b).toy(pump_minus))
        d.add(elm.Line().right().tox(pump_minus))

        # GND
        d.add(elm.Line().down(0.5).at(motor_end))
        d.add(elm.Ground())

        d.add(elm.Label().label('SucuStation — Relay + Pump Circuit\n(identical for Relay 1 → Pump 1 and Relay 2 → Pump 2)', loc='bottom'))

    save(d, '04_relay_pump_circuit')


# ---------------------------------------------------------------------------
# Main
# ---------------------------------------------------------------------------
if __name__ == '__main__':
    print(f'Output directory: {OUTPUT_DIR}\n')
    schematic_power()
    schematic_i2c()
    schematic_esp8266()
    schematic_relay_pump()
    print('\nDone.')

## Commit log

2026-03-26 Initial commit — SniperStation v0.5.0
    Hardware documentation, schematics, BOM, firmware structure, and project planning
    for automated plant watering system built on M5Stack Station ESP32 IoT Development
    Kit (RS485 Version), with Proxmox LXC backend (Mosquitto, InfluxDB, Grafana, Telegram bot).
    [indoor_unit.scad]
2026-03-26 Mark 12V 2A DC adapter as ordered
2026-03-26 Mark Grove cable and LM2596 buck converter as ordered
2026-03-26 Update BOM: mark adapter, buck converters, Wagos, Grove cable as ordered
2026-03-26 Standardize BOM status legend: In hand / Ordered / Pending
2026-03-27 Add Telegram bot with LLM agent and scheduled reports
    - bot.py: command handlers (/start, /estado, /riego, /foto) + NL message handler
    - agent.py: multi-LLM agent loop (Claude/Ollama, selectable via LLM_BACKEND env)
    - tools.py: InfluxDB query tools for all SniperStation sensor data
    - reports.py: daily/weekly/monthly email reports via Resend
    - sniperstation-bot.service: systemd unit with EnvironmentFile secrets injection
2026-03-27 Rewrite bot.py: fix toy code, add MQTT LWT alerts, bilingual EN/ES support
    - Remove unused imports (dotenv_values, threading)
    - Implement MQTT LWT listener in background thread — sends Telegram alert on device offline
    - All user-facing strings moved to STRINGS dict with EN/ES entries, selectable via BOT_LANG env
    - All comments and docstrings in English
2026-03-27 Add /lang command with runtime language switching and disk persistence
    Language stored in /etc/sniperstation/bot_lang, survives restarts.
    /lang shows current, /lang en|es switches and persists immediately.
2026-03-27 Add EN command aliases and dynamic Telegram command menu per language
    - Register /status, /water, /photo as English aliases for ES commands
    - BOT_COMMANDS dict defines menu per language (en/es)
    - set_my_commands called on startup and on every /lang switch
    - Command menu in Telegram updates instantly when language changes
2026-04-07 Add Spanish translations and fix doc language conventions
    - Convert security.md (was in Spanish) to English; add security.es.md
    - Convert sniperstation_project.md (was in Spanish) to English; add .es.md
    - Add Spanish (.es.md) for all hardware docs: BOM, SOURCES, system_overview,
    station485_wiring, esp8266_interior, outdoor_power, indoor_unit_design, requirements
    - Add Spanish (.es.md) for snipermqtt-deployment.md
2026-04-07 Update BOM: all components now in hand
2026-06-20 Add MkDocs docs publishing config
    - mkdocs.yml (Material theme, same-dir plugin, EN/ES nav, source excluded)
    - scripts/gen_mkdocs.py — generates the nav from the doc tree
    - scripts/build-docs.sh — build + deploy to the snipermqtt LXC
    Published at https://snipermqtt.uzc/station/ behind nginx basic auth.
2026-06-21 Fix BOM status legend: distinct symbols per state
    The legend rows all read "In hand" with different meanings; restore
    distinct symbols (in hand / in transit / to buy). All components remain
    in hand. Bump last-updated date.
